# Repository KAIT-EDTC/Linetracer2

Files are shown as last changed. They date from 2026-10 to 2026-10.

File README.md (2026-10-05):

# Linetracer2 — 子ども向け教材ライントレーサー

Raspberry Pi Pico ＋ TC78H653FTG ＋ 130 モーター ×2 の、**全部足付き部品（スルーホール）で子どもが自分ではんだ付けできる**ライントレーサー。
基板そのものがシャーシで、センサー 6 個を基板の裏に直付けし、3D プリント（Bambu Lab P1S）のギヤボックス（1 段 5:1）で 130 モーターを高速に回す。
**テープ・接着剤は使わず、M3 ねじ（2 種類）と 3D プリントのツメで組み立てる。** 部品は秋月・ホームセンター・タミヤ品など、**T 番号のある店で買える定番品だけ**。

| 基板（表） | 組み立て図 |
|---|---|
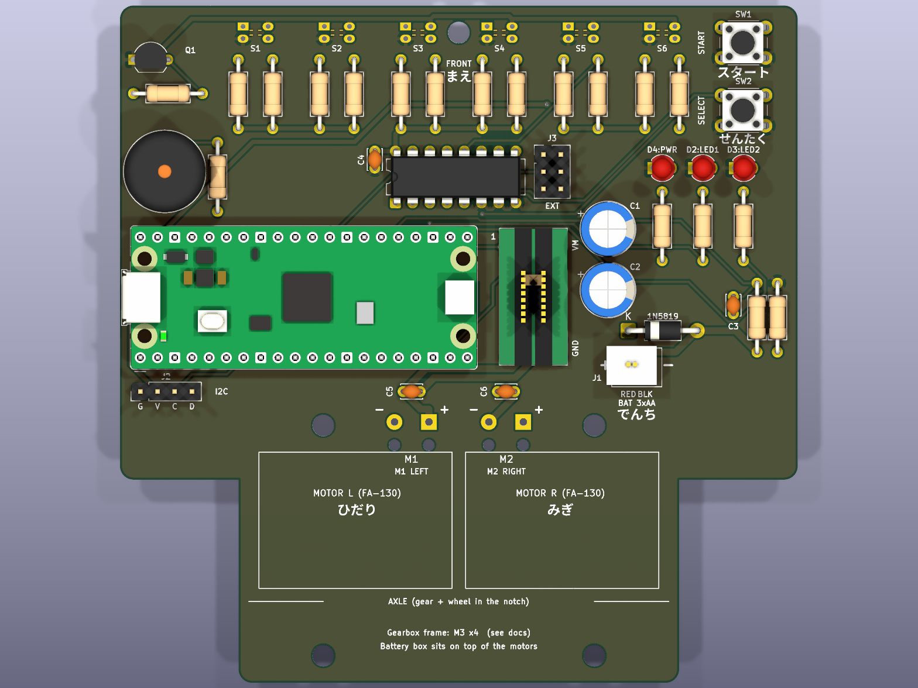
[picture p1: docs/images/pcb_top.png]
PCB top
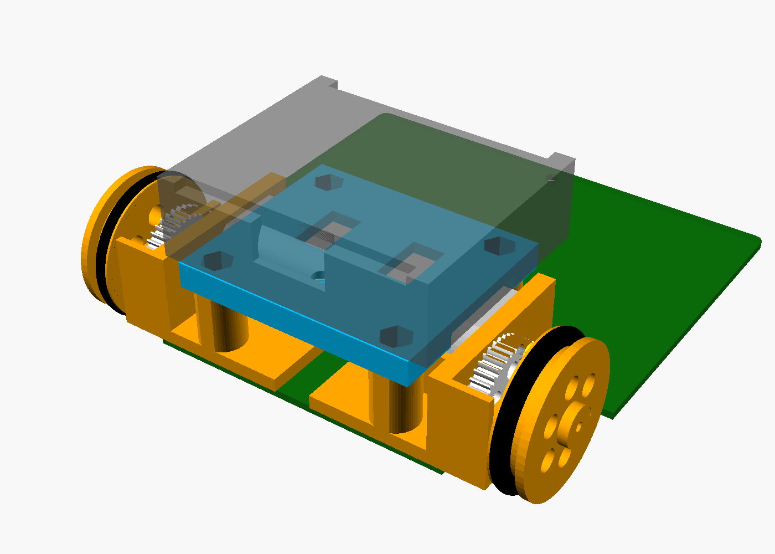
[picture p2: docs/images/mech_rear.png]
mechanics
|  |  |

| 項目 | 内容 |
|---|---|
| マイコン | Raspberry Pi Pico（Pico 2 / Pico W も可）、MicroPython |
| モータードライバ | 東芝 TC78H653FTG（秋月 AE-TC78H653FTG モジュール ¥200、スモールモード 2A×2ch） |
| モーター・駆動 | FA-130RA-2270 ×2、タミヤ 8T ピニオン → 3D プリント 40T（m0.5）1 段 5:1、車輪 φ32（O リング P-24）、車軸 真鍮 φ2 |
| センサー | フォトリフレクタ LBR-123F ×6（TC4051BP で ADC 1 本に切替、外乱光キャンセル付き） |
| 電源 | 単3×3本（アルカリ 4.5V / ニッケル水素 3.6V）。電池ボックスはデッキにねじ止め、スイッチで ON/OFF |
| 基板 | 2 層 100×100 mm、1.6 mm、全部品スルーホール（ピッチ 2.54 mm 以上、センサーのみ 1.8 mm）、**rev.A1** |
| 3D プリント | 枠 L/R・デッキ・平歯車 ×2・車輪 ×2・ツメで差し込むスキッド（PLA 約 30 g、サポート不要）。電池ボックスをツメで留めるデッキも用意（任意） |
| UI | ボタン×2（START/SELECT）、LED×3、圧電ブザー（オプション）、I2C 拡張（OLED を直挿し可） |
| 性能（計算値） | 最高速度 理論 5 m/s（ソフトで 1.5〜2.5 m/s に制限）、加速 4 m/s² でモーター電流 約 1.4 A |
| コスト（1 台） | 全部新品 約 ¥2,370、**Pico を再利用すれば 約 ¥1,500**（`docs/05_bom.md`） |

## 低コスト版「Linetracer2 Lite」（rev.L1）

標準版から部品を減らした版も用意した（詳しくは [lite/README.md](lite/README.md)）。**Lite のファイルはすべて `lite/` フォルダにまとめてあり、標準版のファイルとは混ざらない**。**3D プリント部品・ねじ・モーター・電池ボックスは標準版と共通**で、基板とソフトだけが違う。

| | 標準版 rev.A1 | Lite rev.L1 |
|---|---|---|
| Pico | ピンヘッダで付ける | **基板にじかにはんだ付け**（ヘッダなし） |
| センサー | 6 個 ＋ マルチプレクサ TC4051BP | **3 個を ADC に直結**（マルチプレクサなし） |
| ボタン / LED / ブザー | 2 / 3 / オプション | **1 / 1 / なし**（Pico の緑 LED も使える） |
| タイヤ | O リング P-24 | **TPU の印刷タイヤ** |
| はんだ付け | 約 230 か所 | **約 130 か所** |
| **1 台の部品代（全部新品）** | 約 ¥2,370 | **約 ¥2,060（−¥310、−13%）** |

> ⚠ Lite は Pico をはんだ付けしてしまうので、**Pico を回収して再利用する運用（標準版 約 ¥1,540）はできない**。子どもが持ち帰る講座なら Lite が安い。

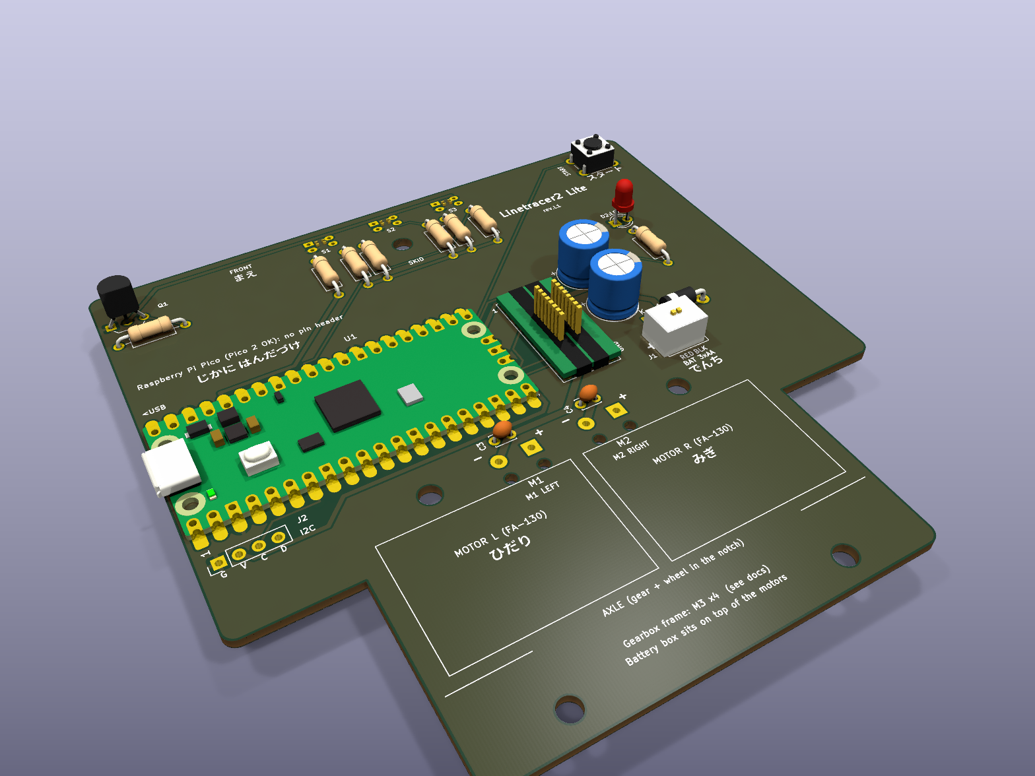
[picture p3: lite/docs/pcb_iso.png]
Lite PCB


## ドキュメント

| ファイル | 内容 |
|---|---|
| [docs/01_requirements.md](docs/01_requirements.md) | 要件定義（依頼内容・派生要件・買い方のルール・コスト目標） |
| [docs/02_concept.md](docs/02_concept.md) | 形・寸法・駆動系の計算・重心・電池 |
| [docs/03_circuit.md](docs/03_circuit.md) | 回路設計（ピン割り当て表、各ブロックの計算） |
| [docs/04_pcb.md](docs/04_pcb.md) | 基板設計（改訂履歴・配置・配線・DRC・発注方法・再生成方法） |
| [docs/05_bom.md](docs/05_bom.md) | 部品表（秋月の通販コード・買う店）、コスト、10 台分の買い物リスト |
| [docs/06_assembly.md](docs/06_assembly.md) | 組み立て手順書（はんだ付けの順番・チェック・ねじ止め・トラブル） |
| [docs/07_firmware.md](docs/07_firmware.md) | ソフトウェア（MicroPython のセットアップ、ライブラリ、PD 制御の調整） |
| [docs/08_knowledge.md](docs/08_knowledge.md) | 知見メモ（部品のクセ、買い方、KiCad/Freerouting/OpenSCAD のハマりどころ、設計判断） |
| [lite/README.md](lite/README.md) | **低コスト版 Lite**（変更点と理由、コスト比較、回路・基板・部品表・組み立て・ソフトの違い） |
| [hardware/mechanical/README.md](hardware/mechanical/README.md) | 3D プリント部品と P1S の印刷設定、ねじの一覧 |
| [hardware/mechanical/assembly.stl](hardware/mechanical/assembly.stl) | 全体を組み立てた 3D（STL、ブラウザで回して見られる） |
| [hardware/kicad/Linetracer2_pcb.step](hardware/kicad/Linetracer2_pcb.step) | 部品付き基板の 3D（STEP、Fusion 等の CAD 用） |
| [docs/Linetracer2_schematic.pdf](docs/Linetracer2_schematic.pdf) | 回路図 PDF |
| [lite/docs/Linetracer2-Lite_schematic.pdf](lite/docs/Linetracer2-Lite_schematic.pdf) | Lite の回路図 PDF |
| [docs/datasheets/README.md](docs/datasheets/README.md) | 使った部品のデータシート（リンク集） |

## フォルダ構成

```
Linetracer2/
├── README.md
├── docs/                     設計資料（Markdown）、回路図/基板 PDF、画像、データシートのリンク
├── hardware/
│   ├── kicad/                KiCad 10 プロジェクト（.kicad_pro / _sch / _pcb）
│   │   ├── lib/              自作シンボル・フットプリント（TC78H653 モジュール、LBR-123F、ブザー等）
│   │   ├── bom/              部品表 CSV（秋月の通販コード入り）
│   │   └── reports/          ERC / DRC レポート、ネットリスト
│   ├── gerber/               製造用 Gerber・ドリル
│   ├── Linetracer2_rev.A1_gerber.zip   ← 基板メーカーにそのまま渡す
│   └── mechanical/           3D プリント部品（OpenSCAD 元データ、STL、組み立て図。両方の版で共通）
├── firmware/micropython/     ライブラリ・標準プログラム・授業用サンプル
├── scripts/                  回路図・基板を生成するスクリプト（再生成用。LT2_VARIANT=lite で Lite も作る）
└── lite/                     ★ 低コスト版 Lite 一式（標準版とは別フォルダ）
    ├── README.md             Lite の設計書（変更点・コスト比較・組み立て・ソフト）
    ├── docs/                 回路図/組立図 PDF、3D 画像
    ├── hardware/             KiCad プロジェクト、Gerber（Linetracer2-Lite_rev.L1_gerber.zip）
    ├── firmware/micropython/ Lite 用ソフト（センサー 3 個・ボタン 1 個・LED 1 個）
    └── scripts/              Lite 専用の生成スクリプト（回路図・配置・シルク）
```

## 状態（2026-10-05, rev.A1）

- [x] 要件定義・構成・駆動系の計算
- [x] 回路図（ERC エラー 0・警告 0）
- [x] 基板レイアウト・配線（DRC エラー 0、未配線 0）、Gerber 出力（rev.A1: ブザーの穴を追加）
- [x] 部品選定・BOM・コスト見積り（T 番号のある店・定番品だけ）
- [x] 3D プリント部品（ねじ止めのデッキ、印刷できる 40T 平歯車、干渉チェック済み）
- [x] MicroPython ライブラリとサンプル
- [ ] **試作 1 台目の製作と実測**（センサーの感度、ギヤのかみ合い、PD ゲイン、電池の持ち）
- [ ] 試作結果を反映した rev.B（`docs/04_pcb.md` §7）
- [x] 低コスト版 Lite rev.L1 の回路図・基板（ERC 0・DRC 0・警告 0）・部品表・ソフト（2026-10-05）
- [ ] Lite の試作（Pico 直付けのしやすさ、3 センサーでの走り、`lite/README.md` §10）

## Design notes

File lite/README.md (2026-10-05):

# 低コスト版「Linetracer2 Lite」（rev.L1）

> 最終更新: 2026-10-05（rev.L1、**未製造・未試作**）
> 標準版（rev.A1）から部品を減らして安くした版。**3D プリント部品・ねじ・モーター・電池ボックス・基板の外形とねじ穴は標準版と共通**で、違うのは基板の中身とソフトだけ。
> **Lite のファイルはすべてこの `lite/` フォルダの中**（下のパスは `lite/` からの相対パス）。標準版のファイル（リポジトリ直下の `hardware/` `docs/` `firmware/`）とは混ざらない。
> 回路図: `hardware/kicad/Linetracer2-Lite.kicad_sch`（PDF: `docs/Linetracer2-Lite_schematic.pdf`）
> 製造データ: `hardware/Linetracer2-Lite_rev.L1_gerber.zip`　ソフト: `firmware/micropython/`
> 部品付き基板の 3D（STEP）: `hardware/kicad/Linetracer2-Lite_pcb.step`　組立図: `docs/Linetracer2-Lite_assembly_top.pdf` / `_bottom.pdf`

| 上面（3D） | 裏面（3D、センサー面） |
|---|---|
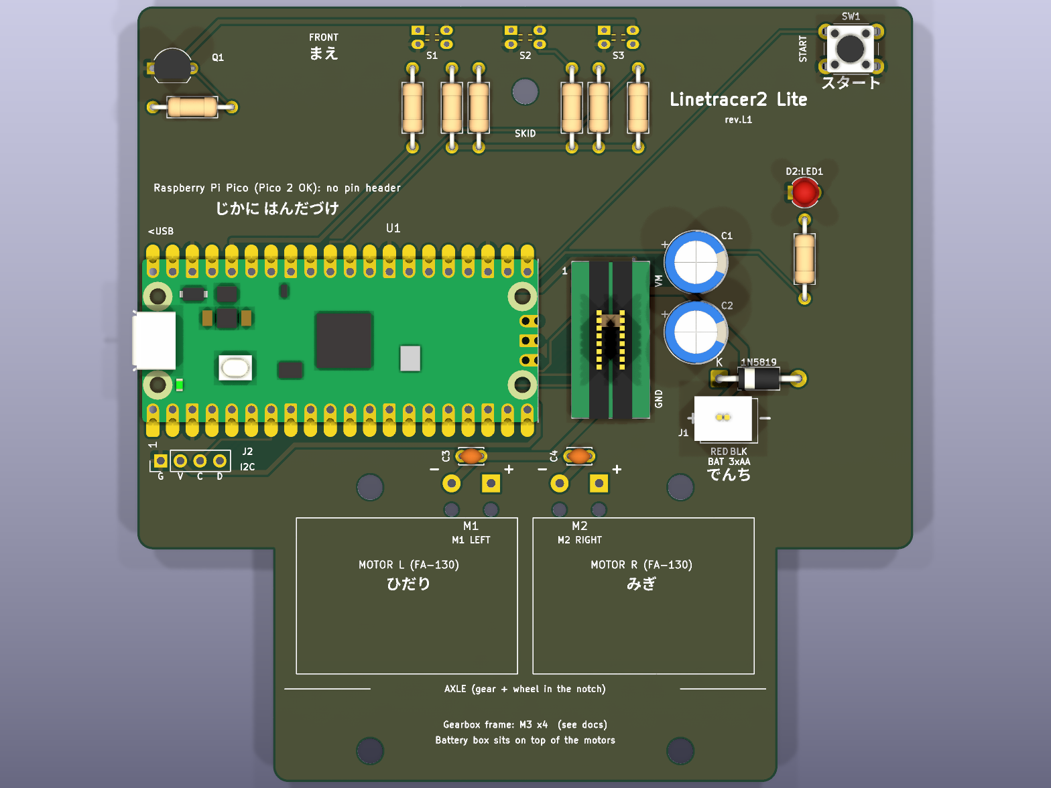
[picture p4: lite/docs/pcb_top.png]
top
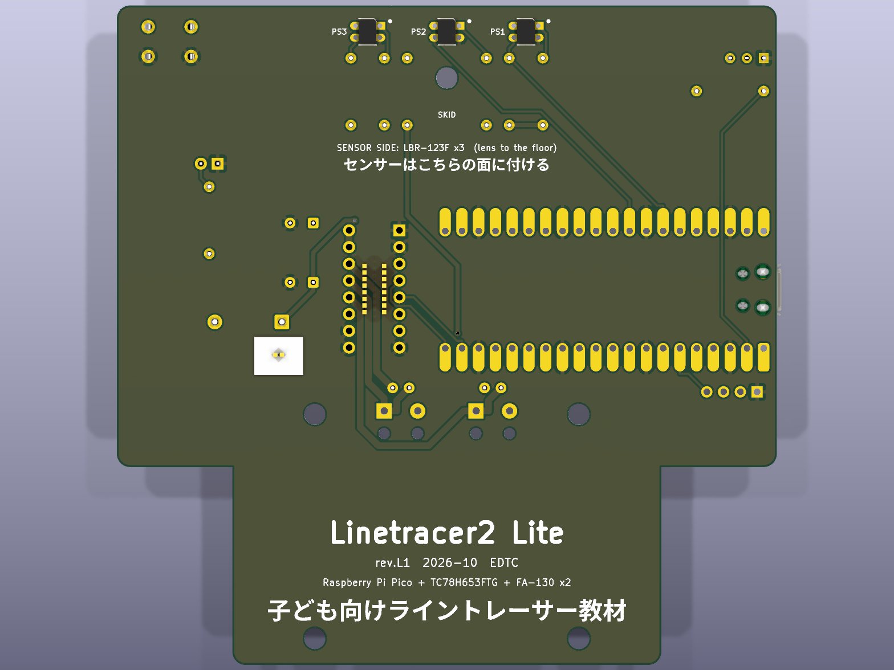
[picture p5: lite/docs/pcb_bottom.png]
bottom
|  |  |

iso

---

## 1. 依頼内容と結論

2026-10-05 の依頼: 「低コスト版を作って。ピンヘッダを付けない／センサーを 3 つに（アナログマルチプレクサいらなくなるかも）／ブザーなし／O リングなしで今ある TPU で作った O リング（タイヤ）を使う／LED 1 個／ボタン 1 個。どれくらい安くなったかも」

| | 標準版 rev.A1 | **Lite rev.L1** | 差 |
|---|---|---|---|
| **1 台の部品代（全部新品）** | 約 ¥2,370 | **約 ¥2,060** | **−¥310（−13%）** |
| Pico 以外の部品代 | 約 ¥1,540 | 約 ¥1,260 | −¥280 |
| はんだ付けの箇所 | 約 230 | **約 130** | −100（約 4 割減） |
| 基板に付ける部品（モーター線のパッドも 1 個と数える） | 44 個 | 24 個 | −20 |
| センサー | 6 個（4051 で切替） | 3 個（ADC に直結、**4051 不要**） | |
| Pico の付け方 | ピンヘッダ（80 か所） | **基板にじかにはんだ付け（40 か所）** | |
| ボタン / LED / ブザー | 2 / 3 / オプション | 1 / 1（＋Pico の LED）/ なし | |
| タイヤ | O リング P-24 | **TPU 印刷タイヤ**（`tire_tpu.stl`） | |
| 電池電圧の測り方 | 分圧抵抗 → GP27 | **Pico の中の VSYS/3（GP29）** | 部品 3 個減 |

- **アナログマルチプレクサ（TC4051BP）は不要になった**。Pico の外部 ADC はちょうど 3 本（GP26/27/28）なので、センサー 3 個を 1 本ずつ直結した。
- その代わり ADC が全部埋まるので、**電池電圧の分圧回路（R13/R14/C3）も外し、Pico の基板の中にある「VSYS/3 → GP29」**で測る（§3.2）。
- 安くなるのは主に「センサー 3 個分 ¥120」「O リング ¥80（TPU 代を引いて −¥65）」「LED・ボタン・コンデンサ・抵抗 ¥75」「ピンヘッダ ¥35」「4051 ¥15」。

### ⚠ Pico を「貸し出し・再利用」する運用だと、かえって高くなる

標準版の「¥1,500 に近づける」案は **Pico を講座で貸し出して再利用する**（基板にピンソケット／ピンヘッダで付け外しする）ことが前提だった（`../docs/05_bom.md` §3 の B 案）。
Lite は Pico を**基板にじかにはんだ付け**するので、**Pico は 1 台に 1 個、使い切り**になる。

| 運用 | 標準版 | Lite |
|---|---|---|
| Pico も持ち帰り（全部新品） | 約 ¥2,370 | **約 ¥2,060（−¥310）** |
| Pico を貸し出して再利用 | 約 ¥1,540 | できない（Pico 込みで約 ¥2,060 → **+¥520**） |

→ **「作ったロボットを子どもが持ち帰る」講座なら Lite が安い**。「Pico は回収して次の講座でも使う」なら標準版のほうが安い。

---

## 2. 変更点の一覧と理由

| # | 変更 | 理由・気をつけたこと |
|---|---|---|
| 1 | **Pico を基板にじかにはんだ付け**（ピンヘッダ ¥35 なし） | Pico は端が「キャスタレーション（半分に切った穴）」になっていて、基板に平らに置いてはんだ付けできる（公式の使い方の一つ）。はんだ付けは 80 → 40 か所。専用フットプリント `RaspberryPi_Pico_DirectSolder` を作った（§4.2） |
| 2 | Pico を標準版より 1 mm 左（基板の端寄り）に | Pico を平らに置くと USB プラグの太い部分が基板の高さまで下がる。USB コネクタの口を基板の端から 0.67 mm 外に出して、プラグが基板に当たらないようにした |
| 3 | **センサー 6 → 3 個**、x = 38 / 50 / 62 mm（12 mm 間隔） | 間隔は標準版と同じ 12 mm。19 mm の線なら、真ん中だけ黒・2 個黒・端だけ黒、の 5 段階で位置が分かる（§7） |
| 4 | **4051 マルチプレクサなし**、S1→GP28、S2→GP27、S3→GP26 | ADC 3 本に直結。基板の上で 3 本の線が交差しない順番にした |
| 5 | 電池電圧は **GP29（Pico 内部の VSYS/3）** で測る | ADC が全部埋まるため。電池電圧 ≒ VSYS + 0.3 V（D1 の電圧降下）。分圧抵抗 2 本とコンデンサ 1 個が減った |
| 6 | **ブザーなし**（BZ1・R18 を削除） | 音の代わりに LED の点滅で知らせる（ソフト） |
| 7 | **LED 1 個**（赤、GP18）。電源ランプ・黄 LED なし | 赤（¥10）は Vf が低く、3.3 V・1 kΩ でも十分光る（標準版の LED1 と同じ部品・同じ GPIO）。電源 ON はソフトで赤 LED を点けて知らせる。**Pico に付いている緑の LED（`Pin("LED")`）も 2 個目の表示に使える**（部品代 0） |
| 8 | **ボタン 1 個**（START、GP16） | 「短く押す＝スタート／ストップ」「長押し＝速さの切り替え」をソフトで分ける |
| 9 | **O リングなし → TPU の印刷タイヤ** | すでにある `tire_tpu.stl`（TPU 95A）を標準にした。車輪 `wheel.stl` は同じ |
| 10 | **スキッドの穴を (50, 4) → (50, 11) に移動** | 真ん中のセンサーが元のスキッドの位置に来るため。センサーの 7 mm 後ろ。スキッドは標準版と同じ**ツメ式**（`skid_clip_h40.stl`、ねじ・ナット不要）をそのまま使う（センサー本体とのすき間は OpenSCAD で確認、わざと 4 mm 前に寄せると重なりを検出） |
| 11 | EXT ヘッダ J3 を削除、I2C の **J2 は穴だけ残す**（ヘッダは買わない） | J3 は 4051 の空きチャンネル用だった。J2 は穴だけなので 0 円。OLED を付けたくなったら 1×4 ヘッダをはんだ付けすればよい |
| 12 | モーターの 0.1 µF（C3/C4）を 1 mm 後ろへ | Pico のパッドが外に伸びた分、間を空けた（はんだのブリッジ防止） |
| 13 | ねじ頭・スキッドのツメの下に「配線禁止エリア」 | 鉄のねじ頭（枠の 4 本、裏面）がレジストを削っても信号線とショートしないように、半径 3.5 mm には配線・ビアを通さない（GND ベタだけ可）。スキッドのツメ（表面に出る返し）の周りも同じく半径 3.6 mm を空けた |

**変えていないもの**: 基板の外形（100×100 mm、後ろの切り欠き）、枠のねじ穴 4 つ、モーター・電源まわりの配置（U2・C1・C2・D1・J1・M1・M2）、3D プリント部品の STL、ねじ（M3×20 ×4、皿 M3×8 ×2）・ツメ式スキッド、ピン番号（モーター・START・LED1・センサー LED は標準版と同じ GPIO）。

---

## 3. 回路

回路図: `docs/Linetracer2-Lite_schematic.pdf`。電源・モータードライバ・センサー 1 個分の回路は標準版と同じ（`../docs/03_circuit.md` §2・§4・§5.1）。

### 3.1 ピン割り当て（Lite）

| GPIO | Pico ピン | ネット名 | つながる先 | 標準版との違い |
|---|---|---|---|---|
| GP1 | 2 | SENS_LED_EN | R7 1kΩ → Q1 ベース（赤外 LED 3 個） | 同じ |
| GP4 / GP5 | 6 / 7 | I2C_SDA / SCL | J2（穴だけ） | 同じ |
| GP11 | 15 | MOT_STBY | U2 STBY | 同じ |
| GP12〜15 | 16, 17, 19, 20 | MOT_IN1〜4 | U2 IN1〜4 | 同じ |
| GP16 | 21 | SW1 | START ボタン（内部プルアップ） | 同じ |
| GP18 | 24 | LED1 | 赤 LED（R8 1kΩ） | 同じ |
| **GP26 / ADC0** | 31 | SENS3 | **右**センサー PS3 | 標準版は 4051 の出力 |
| **GP27 / ADC1** | 32 | SENS2 | **真ん中**センサー PS2 | 標準版は電池電圧 |
| **GP28 / ADC2** | 34 | SENS1 | **左**センサー PS1 | 標準版は EXT |
| GP29 / ADC3 | — | （Pico 内部） | VSYS/3 → **電池電圧** | 新しく使う |
| GP24 | — | （Pico 内部） | VBUS 検出（USB をつなぐと 1） | 新しく使う |
| GP25 | — | （Pico 内部） | Pico の緑 LED | 表示に使ってよい |
| GP0, 2, 3, 6〜10, 17, 19〜22 | | — | 未使用 | ブザー・SW2・LED2・MUX がなくなった |

### 3.2 電池電圧（分圧回路なし）

- Pico / Pico 2 の基板には VSYS を 1/3 にする抵抗（200 kΩ/100 kΩ）があり、GP29（ADC3）で読める（Pico の公式回路）。
- VSYS = 電池 − D1（1N5819）の電圧降下 ≒ 0.25〜0.3 V（150 mA 程度で）。ソフトでは **電池 = VSYS/3 の読み × 3 + 0.3 V** として計算（`linetracer.py` の `D1_DROP`）。誤差 ±0.1 V はモーター電圧の ±3% 程度で、速さの補正には十分。
- **USB をつないでいる間は VSYS ≒ 4.7 V（USB から）になり、電池の電圧は測れない**。GP24（VBUS 検出）で USB を見分け、「USB 接続中は電池チェックしない」ようにした。USB と電池を両方つないだときは、実際より高い電圧と思ってデューティを下げる側（安全側）にずれる。
- **Pico W / Pico 2 W は非推奨**: GP29・GP25 が無線チップ用と共用で、そのままでは電池電圧が読めない（標準版は外付けの分圧で GP27 を使うので W でも動く）。

### 3.3 センサー

- 赤外 LED 3 個 × 約 19 mA = 約 57 mA を Q1（2SC1815）で ON/OFF（外乱光キャンセルは標準版と同じ）。
- 1 回の読み取り: LED 点灯 0.3 ms → 3 個読む → 消灯 0.3 ms → 3 個読む ＝ 約 0.7 ms（標準版は MUX の切替があり約 1 ms）。

---

## 4. 基板

### 4.1 仕様（標準版との比較）

| 項目 | 標準版 rev.A1 | Lite rev.L1 |
|---|---|---|
| 外形・層・板厚 | 100×100 mm、2 層、1.6 mm | **同じ**（3D プリント部品がそのまま付く） |
| フットプリント | 52（取付穴 5 含む） | **30**（取付穴 5、未実装の J2 を含む） |
| パッド / 配線 / ビア | 193 / 300 本 / 5 | **126 / 154 本 / 2** |
| 配線の総延長 | 1,507 mm | **917 mm**（表 566 / 裏 351） |
| ERC / DRC | エラー 0、警告 3（GND の橋配線） | **エラー 0、警告 0、未接続 0** |
| 基板代 | 1 枚 ¥40〜100（JLCPCB 30 枚） | 同じ（大きさが同じなので値段も同じ） |

> **標準版（rev.A1）の基板とは別物**。Lite を作るには Lite の Gerber で基板を発注する。発注の設定は標準版と同じ（`../docs/04_pcb.md` §5）。

### 4.2 Pico 直付けのフットプリント `Linetracer2:RaspberryPi_Pico_DirectSolder`

`../scripts/gen_lib.py`（共通）の `fp_pico_direct()` で作る。

- **1 ピンに 1 つのスルーホールパッド**。穴（φ1.0）は Pico の穴の真下（ピンヘッダでも付けられる）、銅は外側へ伸ばして **Pico の端から 1.9 mm はみ出す**（4.3 × 1.7 mm の長円、穴からのオフセット 1.35 mm）。はんだごてを「基板のパッド」と「Pico の半円の穴」に同時に当てられる。
- KiCad 標準の `RaspberryPi_Pico_Common_Unspecified` から次をコピー:
  - **Pico の裏の USB コネクタの足が出る所の穴**（4 つ、銅なし）
  - **Pico の裏のむき出しのテストパッド（TP1〜TP7、デバッグ端子）の下の銅禁止エリア**（配線・ビア・ベタを置かない。Pico の裏の銅と基板の配線がショートしないように）。USB の足の穴が TP2・TP3 のエリアに少しかかるので、このエリアは「穴は可」に変えた
- 3D モデルはピンヘッダなしの `RaspberryPi_Pico.step`。

### 4.3 配置

```
 前 ─────────────────────────────────────────────────
  Q1 R7       FRONT   [S1]   [S2]   [S3]        SW1 START
                      R1 R4  R2 (SKID) R5  R3 R6      Linetracer2 Lite
                             ●(50,11)
  Raspberry Pi Pico : じかに はんだづけ                 D2 LED1
 ┌─(USB 左端)──── Pico（平らに置く）────────┐ ┌U2┐ C1     R8
 │                                           │ │  │ C2
 └───────────────────────────────────────────┘ └──┘ D1 1N5819
  J2(I2C 穴だけ)          C3  M1(+-)   C4  M2(+-)   J1(電池)
 ───(切欠)── [モーター L] [モーター R] ──(切欠)──
 後
```

- 真ん中のセンサー PS2 の抵抗（R2・R5）は、スキッドをよけて x = 44 / 56 に置いた。左右のセンサーの抵抗は標準版と同じく真後ろ。
- 空いた右前の場所に「Linetracer2 Lite」と印刷。
- 基板の生成手順・自動配線は標準版と同じ（6 回試して最短を採用、§9）。

---

## 5. 部品表（1 台分）

機械可読の部品表: `hardware/kicad/bom/Linetracer2-Lite_bom.csv`。価格は `../docs/05_bom.md` と同じ（秋月 2026-10-05 確認、≒ は目安）。

### 5.1 基板に載る部品（すべて秋月）

| 記号 | 部品 | 数 | 秋月 通販コード | 単価 | 小計 | 標準版との差 |
|---|---|----|---|---|---|---|
| U1 | Raspberry Pi Pico（Pico 2 も可、W は不可） | 1 | 116132 | ¥800 | ¥800 | ピンヘッダ不要（−¥35） |
| U2 | モータードライバーモジュール AE-TC78H653FTG | 1 | 114746 | ¥200 | ¥200 | 付属の 1×8 ピンヘッダ 2 本を使う（追加費用なし） |
| PS1〜PS3 | フォトリフレクタ LBR-123F | 3 | 116455 | ¥40 | ¥120 | −3 個（−¥120） |
| Q1 | トランジスタ 2SC1815-GR | 1 | 117089（20 個 ¥100） | ¥5 | ¥5 | |
| D1 | ショットキーダイオード 1N5819 | 1 | 117244（10 個 ¥100） | ¥10 | ¥10 | |
| R1〜R3 | 抵抗 100Ω（茶黒茶） | 3 | 125101（100 本 ¥200） | ¥2 | ¥6 | −4 本 |
| R4〜R6 | 抵抗 10kΩ（茶黒橙） | 3 | 125103（100 本 ¥100） | ¥1 | ¥3 | −5 本 |
| R7, R8 | 抵抗 1kΩ（茶黒赤） | 2 | 125102（100 本 ¥100） | ¥1 | ¥2 | −2 本 |
| C1, C2 | 電解コンデンサ 470µF 16V | 2 | 108426 | ¥10 | ¥20 | |
| C3, C4 | 積層セラミック 0.1µF（モーター用） | 2 | 113582（10 個 ¥100） | ¥10 | ¥20 | −2 個 |
| D2 | LED 3mm 赤 | 1 | 111577 | ¥10 | ¥10 | −2 個（黄・黄緑） |
| SW1 | タクトスイッチ 6mm | 1 | 108075 | ¥10 | ¥10 | −1 個 |
| J1 | XH ベース付ポスト 2P | 1 | 112247 | ¥10 | ¥10 | |
| J2 | （I2C の穴。**何も付けない**） | — | — | — | — | |
| | | | | | **¥1,216** | 標準版 ¥1,461 → **−¥245** |

使わなくなった部品: ピンヘッダ 1×40（100167）、TC4051BP（110914）、LED 黄（111639）・黄緑（111637）、圧電スピーカー（104118、オプション）。

### 5.2 機械部品

| 部品 | 数 | 買う所 | 小計 | 標準版との差 |
|---|----|---|---|---|
| DC モーター FA-130RA-2270 | 2 | 秋月 106437 | ¥300 | |
| 電池ボックス 単3×3 スイッチ・XH 付 | 1 | 秋月 112243 | ¥130 | |
| タミヤ 8T ピニオン（15289） | 2 | 模型店・ヨドバシ・Amazon | ¥77 | |
| 真鍮丸棒 φ2 × 20 mm | 2 | ホームセンター | ≒¥15 | |
| **TPU タイヤ（`tire_tpu.stl`）** | 2 | P1S で印刷（TPU 95A、2 本で約 2.1 cm³ ≒ 2.5 g） | ≒¥15 | O リング ≒¥80 の代わり（**−¥65**） |
| 3D プリント部品（PLA） | 1 式 | P1S | ≒¥90 | 同じ（STL 共通） |
| なべ小ねじ M3×20 | 4 | ホームセンター | ≒¥60 | |
| 皿小ねじ M3×8 | 2 | ホームセンター | ≒¥20 | （電池ボックス用） |
| 六角ナット M3（鉄） | 6 | ホームセンター／秋月 114372 | ≒¥50 | |
| スキッド | 1 | ツメ式（`skid_clip_h40.stl`）を印刷 | （PLA 代に含む） | 標準版と同じ |
| モーター用の電線 | 少々 | | ≒¥10 | |
| | | | **≒¥767** | 標準版 ≒¥832 → **−¥65** |

> TPU の値段は 1 kg ¥5,000 前後（¥5/g）として計算。サークルにあるフィラメントを使えば実際の出費は 0 円。

### 5.3 合計

| | 標準版 rev.A1 | Lite rev.L1 | 差 |
|---|---|---|---|
| 基板に載る部品 | ¥1,461 | ¥1,216 | −¥245 |
| 基板（JLCPCB 30 枚の目安） | ¥80 | ¥80 | 0 |
| 機械部品 | ≒¥832 | ≒¥767 | −¥65 |
| **合計（全部新品）** | **約 ¥2,370**（¥2,373） | **約 ¥2,060**（¥2,063） | **−¥310（−13%）** |
| 参考: Pico 以外 | 約 ¥1,540 | 約 ¥1,260 | −¥275 |
| 参考: 標準版でブザーも付けていた場合 | 約 ¥2,400 | 約 ¥2,060 | −¥340 |

- **¥1,500 には届かない**。いちばん大きいのは相変わらず Pico ¥800（全体の 39%）。
- 10 台分なら約 **¥3,100 安くなる**。はんだ付けの時間も約 4 割減る（§6）。

### 5.4 授業 10 台分の買い物リスト（Lite）

| 店 | 品物（通販コード） | 数 |
|----|---|----|
| 秋月 | Pico 116132 ×10、AE-TC78H653FTG 114746 ×10、LBR-123F 116455 ×30、2SC1815 117089 ×1 袋、1N5819 117244 ×1 袋、抵抗 125101・125103・125102 ×各 1 袋、470µF 108426 ×20、0.1µF 113582 ×2 袋、LED 赤 111577 ×10、タクトスイッチ 108075 ×10、XH ポスト 112247 ×10、電池ボックス 112243 ×10、FA-130RA 106437 ×20 | |
| 模型店・ヨドバシ・Amazon | タミヤ 15289 ×3 袋（真ちゅうだけ使うなら ×5 袋） | |
| ホームセンター | 真鍮丸棒 φ2 ×1 本、なべ小ねじ M3×20 ×40、皿小ねじ M3×8 ×20、六角ナット M3 ×60、（電線） | |
| ヨドバシ・Amazon | PLA フィラメント（300 g 程度）、TPU 95A（サークルの手持ちでよい、10 台で約 25 g） | |

（O リング・ピンヘッダ・TC4051BP は買わなくてよい）

---

## 6. 組み立て（標準版 `../docs/06_assembly.md` との違い）

はんだ付けの箇所: **Pico 40 ＋ モジュール 32 ＋ センサー 12 ＋ 抵抗 16 ＋ その他 21 ＋ モーター線 8 ＝ 約 130 か所**（標準版 約 230）。

### 6.1 Pico を基板にじかにはんだ付けする（いちばん大事）

> **やり直しがきかない**ので、はじめての子は先生がとなりで見る。低学年なら先生が先に付けておく。

1. **先に MicroPython を書き込んで、動くことを確かめておく**（`../docs/07_firmware.md` §1。はんだ付けした後でも書き込めるが、不良品を付けてしまうと外すのが大変）。
2. Pico を**部品面を上**にして、**USB が基板の左端に来る向き**で枠の中に置く（逆向きだと USB が基板の上に乗るのですぐ分かる）。40 個の半円の穴が、基板の 40 個の細長いパッドの真ん中に乗るように位置を合わせる。
3. Pico を指（または洗濯ばさみ）で押さえ、**対角の 2 か所（1 番と 21 番など）だけ先にはんだ付け**。Pico が浮いていないか横から見る。浮いていたら、その 1 か所を温め直しながら押さえる。
4. 残りを 1 か所ずつ: こて先を**基板のパッド（Pico の外にはみ出した所）と半円の穴の両方**に当てて 2 秒 → はんだを当てる → 半円の穴にはんだが吸い上がって山になればよい。
5. 全部付けたら、**となりのピンとのブリッジ（はんだがつながっていないか）**をルーペで見る。つながっていたら、はんだ吸い取り線で取る。
6. Pico の裏に USB コネクタの足が出ていても、基板の穴に逃げるので Pico は浮かない（はんだ付け不要）。

### 6.2 その他の違い

| 標準版の手順 | Lite |
|---|---|
| 4051（IC）・J3・ブザー・SW2・LED 2 個・R13〜R19 | **ない**（とばす） |
| センサー 6 個 | 3 個（PS1〜PS3、**基板の裏**に付けるのは同じ） |
| スキッド（ツメ式）は (50, 4) の穴 | 同じツメ式スキッドを **(50, 11) の穴**（真ん中のセンサーの 7 mm 後ろ、シルクに SKID）に押し込む |
| タイヤは O リング P-24 | **TPU の印刷タイヤ**を車輪のみぞにはめる（引っぱって伸ばしながら） |
| 電源ランプ D4 で電源 ON を確認 | 電源ランプはない。**電池のスイッチを入れて `main.py` が動くと赤 LED が点く** |
| モーターモジュールのヘッダ | 同じ（モジュールに付属のヘッダを使う） |

### 6.3 最初の確認（テスター）

1. 電池を入れずに、J1 の + と − の間がショートしていないか（標準版と同じ）。
2. Pico の 40 本のうち、**となりどうしがつながっていないか**（特に GND のとなり: 3・8・13・18・23・28・33・38 番）。
3. USB をつなぎ、Thonny で `examples/01_led_blink.py` → 赤 LED と Pico の緑 LED が交互に光れば Pico のはんだ付けは OK。

---

## 7. 性能への影響（3 センサーにしたこと）

| 項目 | 標準版（6 個） | Lite（3 個） |
|---|---|---|
| 線を見つけられる幅（19 mm 線） | 中心から ±39.5 mm | **±21.5 mm** |
| 位置の分かり方 | 6 段階＋各センサーの境目で連続的 | **5 段階**（左だけ／左＋中／中だけ／中＋右／右だけ）＋境目 |
| 位置の値 | −2500〜+2500 | −1000〜+1000（1000 = センサー 1 個分 = 12 mm は同じ） |
| 1 回の読み取り | 約 1 ms | 約 0.7 ms |
| 前の荷重（スキッド、見積り） | 約 44 g | 約 43 g（部品が減った分とスキッドが後ろに下がった分がほぼ相殺） |

- **急なカーブを速く曲がるのは苦手になる**（線がセンサーの外に出やすい）。見失ったら最後に見えた側へ強く曲がる処理は標準版と同じなので、ゆっくりならたいていのコースは走れるはず。
- ソフトの Kp は、最大の誤差が ±1000 しかないので標準版の約 2 倍を初期値にした（`main.py` の `LEVELS`）。**実機で調整が必要**（`../docs/07_firmware.md` §4 の手順と同じ）。
- 3 個だと位置が階段状に変わるので、D（微分）の値をなめらかにするフィルタを入れた（`d_f`）。
- 線幅が 15 mm でも 25 mm でも動く間隔（12 mm）にしてある。線幅が決まっていて 19 mm より太いなら、間隔を広げると見つけられる幅が増える（`gen_pcb_lite.py` の `SENSOR_X`）。

---

## 8. ソフト（`firmware/micropython/`）

標準版と同じ書き方で使えるように作った。違う所だけ:

```python
from linetracer import Robot
robot = Robot()

v = robot.sensors.read()        # [S1, S2, S3] 0(白)〜1000(黒)
pos = robot.sensors.position()  # -1000(左)〜0(真ん中)〜+1000(右)、見失うと None
kind = robot.wait_press()       # ボタンを押して離すまで待つ → "short" か "long"（0.8 秒以上）
robot.blink(3)                  # 赤 LED を 3 回点滅（ブザーの代わり）
robot.led_pico.value(1)         # Pico の緑 LED（2 個目の表示）
robot.battery.read()            # 電池電圧 [V]（USB 接続中は測れない → robot.battery.usb() で確認）
```

| 標準プログラム `main.py` | 操作 |
|---|---|
| START を短く押す（1 回目） | 自動キャリブレーション（線の上で左右に回る） |
| START を短く押す（2 回目から） | 赤 LED が 3 回点滅して走り出す。もう一度押すと止まる |
| START を長押し（Pico の緑 LED が点いたら離す） | 速さのレベル 1→2→3→1。赤 LED がレベルの数だけ点滅 |
| 赤 LED が点きっぱなし | 準備 OK（電源ランプの代わり） |
| 赤 LED が速く 5 回点滅 | 電池が少ない |

授業のサンプル: `01_led_blink.py`（赤と緑の LED）、`02_button.py`（ボタン・押した回数）、`03_sensor_monitor.py`（3 個の値）、`04_motor_test.py`（標準版と同じ）、`05_simple_tracer.py`（S1 と S3 で ON/OFF 制御）。

> 標準版の `../firmware/micropython/` は Lite では動かない（ピンと ADC の使い方が違う）。逆も同じ。

---

## 9. 作り直し方（スクリプト）

共通のスクリプト（リポジトリ直下の `scripts/`）に環境変数 `LT2_VARIANT=lite` を付けると、出力先が `lite/hardware/` になる。付けなければ標準版。Lite 専用のスクリプトは `lite/scripts/` にある。コマンドはリポジトリ直下の `scripts/` で実行する。

```bash
cd scripts
export LT2_VARIANT=lite
python3 gen_lib.py && python3 gen_3d.py && python3 gen_lib.py   # 2 回目で 3D モデルがフットプリントに入る
./kc fp upgrade ../lite/hardware/kicad/lib/Linetracer2.pretty && ./kc sym upgrade ../lite/hardware/kicad/lib/Linetracer2.kicad_sym
python3 gen_project.py
python3 ../lite/scripts/gen_schematic_lite.py && ./kc sch upgrade ../lite/hardware/kicad/Linetracer2-Lite.kicad_sch
./kc sch export netlist --format kicadsexpr -o ../lite/hardware/kicad/reports/Linetracer2-Lite.net ../lite/hardware/kicad/Linetracer2-Lite.kicad_sch
python3 build_pcb.py 6          # 配置（lite/scripts/gen_pcb_lite.py）→ 自動配線 → シルク（lite/scripts/post_pcb_lite.py）→ DRC、約 5 分
./kpy sync_pcb.py
./export_outputs.sh             # Gerber・BOM・PDF・STEP・3D 画像（lite/hardware/, lite/docs/）
```

| ファイル | 役目 |
|---|---|
| `scripts/kicad_env.py`（共通） | `LT2_VARIANT` で出力先（`hardware/kicad/` か `lite/hardware/kicad/`）とプロジェクト名を切り替え |
| `lite/scripts/gen_schematic_lite.py` | Lite の回路図 |
| `lite/scripts/gen_pcb_lite.py` | Lite の部品配置（`scripts/gen_pcb.py` の関数を使い、配置だけ差し替え）＋ねじ頭・スキッドのツメの下の配線禁止エリア |
| `lite/scripts/post_pcb_lite.py` | Lite のシルク |
| `scripts/gen_lib.py`（共通） | Pico 直付けフットプリントを追加（両方の版で共通のライブラリ） |
| `hardware/mechanical/linetracer2_mech.scad`（共通） | `-D LITE=true` でスキッド位置・センサー・TPU タイヤを Lite にして干渉チェック |

## 10. まだ確かめていないこと（試作で見る）

- [ ] Pico の直付けを子どもができるか（パッドの長さ 1.9 mm で足りるか、ブリッジしないか）
- [ ] USB プラグが基板の端に当たらないか（ケーブルの形による。当たるなら Pico をもう 0.5 mm 左へ）
- [ ] 3 センサーでどのくらいの速さ・カーブまで走れるか（`LEVELS` の調整）
- [ ] GP29 で読んだ電池電圧が、テスターで測った電池電圧と ±0.1 V で合うか（合わなければ `D1_DROP` を直す）
- [ ] TPU タイヤの外径（31.2 mm）で、センサーと床の距離がちょうどよいか（スキッド 3.5 / 4.0 / 4.5 mm で調整）
- [ ] 長押し 0.8 秒が子どもに分かりやすいか

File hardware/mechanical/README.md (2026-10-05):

# 3D プリント部品（Linetracer2 rev.A1）

サークルの **Bambu Lab P1S（0.4 mm ノズル）** で印刷する前提。STL は**印刷する向きで**書き出してあるので、Bambu Studio に読み込んでそのまま並べればよい（回転不要・サポート不要）。

assembly

| 分解図 | 側面 | ツメ版デッキ（任意） | ツメのスキッド |
|---|---|---|---|
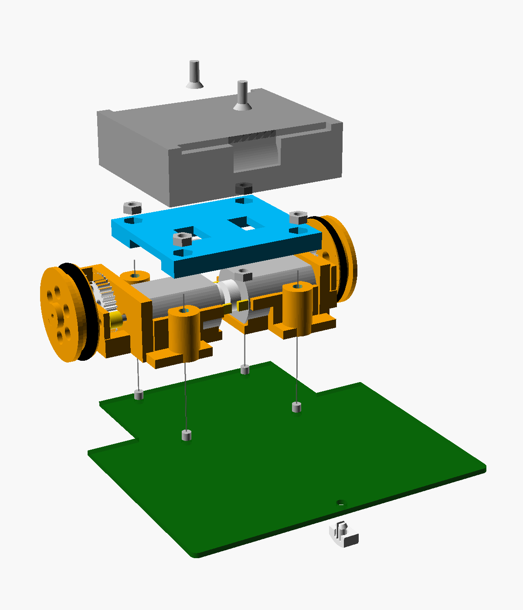
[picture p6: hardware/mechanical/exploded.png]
exploded
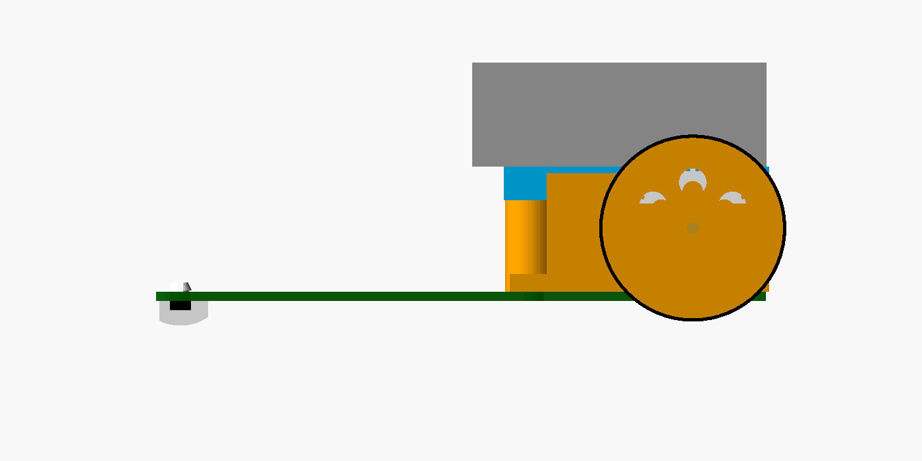
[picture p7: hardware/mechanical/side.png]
side
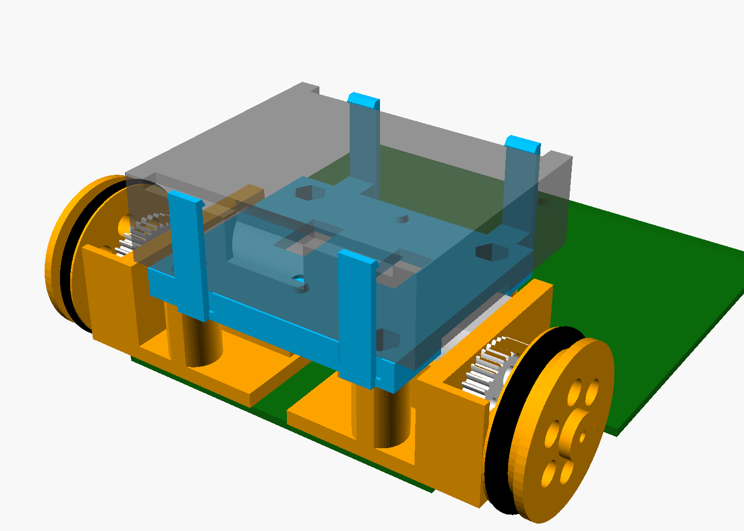
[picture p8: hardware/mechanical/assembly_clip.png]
clip
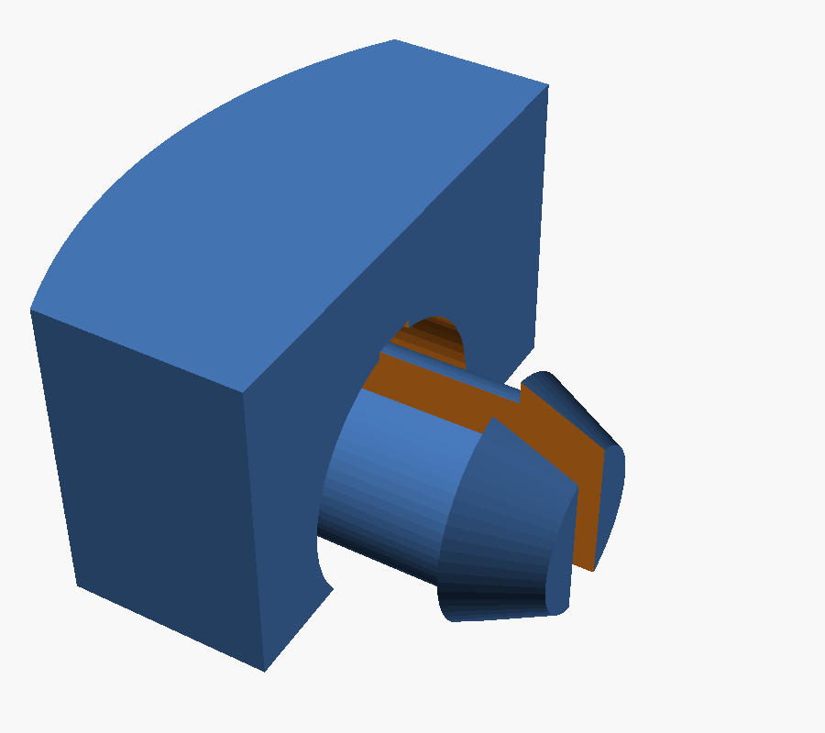
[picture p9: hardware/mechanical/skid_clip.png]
skid
|  |  |  |  |

## 1. 部品と印刷設定（1 台分）

| ファイル | 部品 | 数 | 材料 | Bambu Studio の設定 | 体積 |
|---|---|----|---|---|---|
| `frame_left.stl` / `frame_right.stl` | ギヤボックス枠（モーターのゆりかご＋軸受け＋柱） | 各 1 | PLA | 0.20 mm Standard、壁 3、インフィル 30%、サポートなし | 8.9 cm³ ×2 |
| `deck.stl` | デッキ（電池ボックスの台。モーターの押さえも兼ねる） | 1 | PLA | 0.20 mm Standard、壁 3、インフィル 25%。**上下逆さ（電池側がベッド）**で書き出し済み | 7.7 cm³ |
| `gear40.stl` | 平歯車 40T（m0.5） | 2 | PLA | **0.08 mm Extra Fine**、壁 4、インフィル 40%（壁の生成はクラシック・Arachne どちらでもよい）。ハブが上 | 1.0 cm³ ×2 |
| `wheel.stl` | 車輪（O リング P-24 をはめる） | 2 | PLA | 0.16 mm、壁 3、インフィル 40%。ハブが上 | 3.4 cm³ ×2 |
| `skid_clip_h40.stl` | **スキッド（ツメで差し込む、高さ 4.0 mm、標準）** | 1 | PETG（PLA も可） | 0.12 mm、壁 3、インフィル 40%。**横倒し**で書き出し済み（ツメが層に沿って曲がるので折れにくい） | 0.14 cm³ |
| `skid_clip_h35.stl` / `skid_clip_h45.stl` | 同（センサー高さ調整用 3.5 / 4.5 mm） | 予備 | 同上 | 同上 | |
| `skid_screw_h40.stl` | スキッド（ねじ止め版。ツメが折れたときの予備：M3×8 皿＋ナイロンナット） | (1) | 同上 | 0.12 mm、平らな面がベッド | 0.2 cm³ |
| `caster_print_h40.stl` | **ボールキャスター（試作・任意）: 玉ごと一度に印刷**（スキッドの代わり。玉は φ4、中で転がる） | (1) | PETG（PLA も可） | 0.12 mm、壁 3、インフィル 40%。**横倒し**で書き出し済み。玉と受けは最初から別々（はがす作業なし） | 0.23 cm³ |
| `caster_bead_h40.stl` | **ボールキャスター（試作・任意）: 受けだけ印刷、玉はダイソーのパール調ビーズ φ6** | (1) | PETG（PLA も可） | 同上 | 0.24 cm³ |
| `deck_clip.stl` | **ツメ版デッキ（任意・試作）**: 電池ボックスをねじではなく 4 本のツメで押さえる | (1) | PLA / PETG | 0.20 mm、壁 3、インフィル 25%。**そのままの向き（ツメが上）** | 9.0 cm³ |
| `tire_tpu.stl` | TPU タイヤ（O リングの代わり、任意） | (2) | TPU 95A | 0.20 mm、インフィル 100%、ゆっくり | 1.0 cm³ |
| `linetracer2_mech.scad` | 上記の元データ（OpenSCAD、寸法はすべてパラメータ） | — | | | |
| `assembly.stl` | **全体を組み立てた状態の 3D**（見る用。基板・モーター・電池ボックスは簡略形状、印刷しない） | — | | GitHub 上でそのまま回して見られる | |

- 1 台分 約 35 cm³（PLA 約 30 g、¥90 前後）。256 mm 角のベッドに **2〜3 台分を一度に**並べられる。
- 平歯車だけ設定が違う（細かい層）ので、**平歯車は別のプレート**にまとめて印刷する。
- 0.2 mm ノズルを持っていれば、平歯車は「0.2 mm ノズル・0.06 mm」で印刷すると歯の形がもっときれいになる（必須ではない）。

### 印刷時間の目安（Bambu Studio 2.08 の P1S 0.4 mm プロファイルでスライスした値、1 個ずつ）

| 部品 | 設定 | 時間 |
|---|---|---|
| 枠 L / R | 0.20 mm | 約 21 分 ×2 |
| デッキ | 0.20 mm | 約 16 分 |
| 車輪 | 0.16 mm | 約 13 分 ×2 |
| 平歯車 40T | 0.08 mm（壁 4・インフィル 40%） | 約 17 分 ×2 |
| スキッド（ツメ） | 0.12 mm | 約 3.5 分 |
| （ボールキャスター 玉ごと／ビーズ用） | 0.12 mm（PETG） | 約 4.5 分 ／ 約 4.5 分 |
| （ツメ版デッキ） | 0.20 mm | 約 23 分 |
| **1 台分** | | **約 2 時間**（まとめて並べるともう少し短い） |

### 平歯車は印刷できるか（スライス結果で確認済み、2026-10-05）

m0.5 の歯は先端の幅が約 0.28 mm で、0.4 mm ノズルの線（0.42 mm）より細い。そこで実際に Bambu Studio（CLI）で P1S 用にスライスし、G コードから**各層・各歯の外壁の通り道の半径**を測った。

| 壁の生成 | 結果（z = 0.24〜3.92 mm の 5 層） |
|---|---|
| クラシック（P1S プロファイルの既定） | **40 枚すべての歯が先端まで印刷される**（外形 r 約 10.50 mm、設計 10.50 mm） |
| Arachne | 同じく 40 枚すべて先端まで出る |

> 訂正（2026-10-05）: 最初の解析では「Arachne だと歯が欠ける」と書いたが、G コードの円弧命令（G2/G3、Bambu は多用する）を読み飛ばしていたための誤りだった。円弧も読む解析でやり直した結果が上の表。どちらの設定でもよい。

## 2. 固定のしかた（ねじとツメ。テープ・接着剤は使わない）

| 場所 | 固定 | 部品 | 理由 |
|---|---|---|---|
| 基板 ↔ 枠 ↔ デッキ | **ねじ** | なべ小ねじ M3×20 ×4、ナット ×4（デッキに埋める） | ロボットの重さ・ぶつかった衝撃・モーターの振動を全部受ける所。PLA のツメは荷重がかかり続けると少しずつ伸びて（クリープ）ゆるむ。またツメで基板をつかむには基板の下に回り込む形が要り、枠を平らに置いて印刷できなくなる（サポートが要り、層の向きも弱い） |
| 電池ボックス ↔ デッキ | **ねじ（標準）** または **ツメ（任意）** | 皿小ねじ M3×8 ×2、ナット ×2 ／ ツメ版デッキ `deck_clip.stl` | ねじは電池ボックスに元からある穴を使うので確実。ツメ版はねじ不要だが、電池ボックスの壁の高さ（データシートで 15.0 ±0.5 mm）に合わせる必要がある（§2.1） |
| スキッド ↔ 基板 | **ツメ（標準）** | なし（`skid_clip_h40.stl` を穴に押し込むだけ） | 床がスキッドを基板に押し付けるので、ツメは「落ちない」だけでよい。買いにくいナイロンナットが要らなくなった |
| モーター ↔ 枠 | ツメ（はめ込み）＋デッキで押さえる | — | 以前と同じ |

買う所: なべ小ねじ M3×20（ホームセンター／秋月 107437）、皿小ねじ M3×8（ホームセンター）、六角ナット M3（ホームセンター／秋月 114372）。

### 2.1 ツメ版デッキ（任意）の使い方

- 電池ボックスの**底の 2 つの穴にデッキの突起（φ3.2）が入って位置が決まり**、長い側の壁の上を **4 本のツメ**が押さえる。電池の出し入れのじゃまにはならない（ツメは壁の上にだけかかる）。
- **先に電池ボックスの壁の高さを測る**: ノギスで、ボックスの底から長い側の壁の上（両端の柱と真ん中の切り欠きの間の平らな所）まで。15.0 mm でなければ `linetracer2_mech.scad` の `BOX_SHOULDER_H` をその値にして `deck_clip.stl` を書き出し直す。
- 印刷はそのままの向き（ツメが上）。ツメは高さ方向に長い（約 20 mm）ので、曲げてもひずみは約 0.5% と小さい。PLA で折れる場合は PETG にする。
- 入れ方: 電池を抜いたボックスを上から押し込む（ツメが外に開いてパチッと閉じる）。外すときは前後のツメを外側に開いて持ち上げる。

### 2.2 ツメのスキッドの使い方

- 基板の裏から `SKID` の穴に押し込む（2 本に割れたピンがすぼまって通り、表に出たところで開いて抜けなくなる）。
- 外すときは基板の表に出たピンの先を指（またはラジオペンチ）でつまんで、すぼめながら裏へ押し出す。
- 印刷は横倒しの向き（書き出したまま）。ピンの割れ目 0.8 mm がスライス後も開いていることを G コードで確認済み。

### 2.3 ボールキャスター（試作・任意）

スキッド（そり）の代わりに、前を**転がる玉**で支える試し用。スキッドと同じ `SKID` の穴にツメで差し込む。

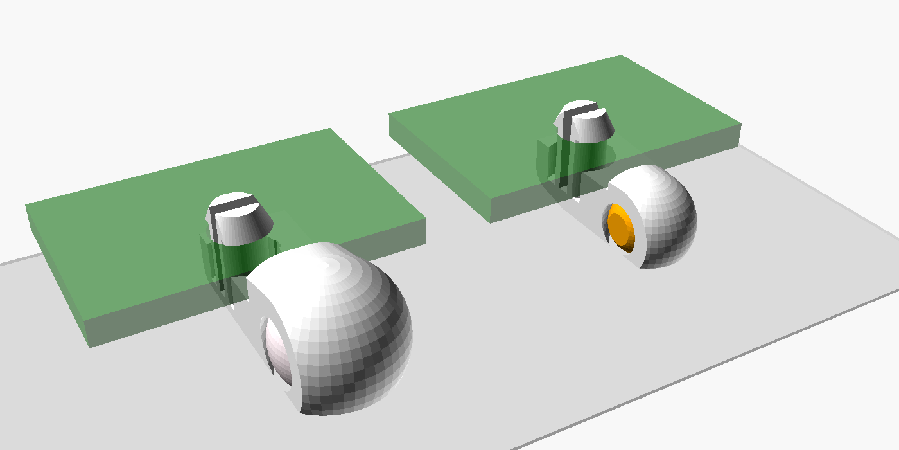
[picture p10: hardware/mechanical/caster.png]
caster


（左: ビーズ版、右: 玉ごと印刷版。緑は基板の前の端）

- 玉と受けは基板と床のすき間（4.0 mm）に入らないので、**玉は基板の前の端のすぐ前**に出し、基板の下のそり形の腕でピンまでつなぐ。腕は PS3・PS4 の間（幅 5 mm）を通る。
- 高さはスキッドの標準と同じ 4.0 mm（基板の下面〜床）。3.5 / 4.5 mm にするときは `SKID_H` を変えて書き出す。
- **標準版の基板専用**。Lite（`lite/`）はスキッドの穴が基板の端から 11 mm 奥にあり、腕が真ん中のセンサーの下を通ってしまうので使えない。

| | `caster_print_h40.stl`（玉ごと印刷） | `caster_bead_h40.stl`（ビーズ） |
|---|---|---|
| 玉 | **φ4** を受けの中で一緒に印刷（すき間 0.35 mm、玉の上は 0.55 mm） | **ダイソーのパール調ビーズ φ6** を床側から押し込む |
| 大きさ | ツメのスキッドと同じ幅 5 mm に収まり、**基板の上面より低い**。前への出っぱりは基板の端から 4.7 mm | 幅 7 mm、基板の上面より 1.6 mm 高い。前への出っぱり 7.6 mm |
| 接地点 | 基板の端の 1.5 mm 前（センサーの列の 5.5 mm 前） | 基板の端の 3.5 mm 前（センサーの列の 7.5 mm 前） |
| 床〜受けの下面 | 0.55 mm | 1.16 mm |
| 部品 | 1 個 | 受け 1 個 ＋ ビーズ 1 個 |
| 予想 | 積層の段差とベッド側の小さな平ら（φ1.9、高さ 0.25 mm）があり、なめらかには転がらない。スキッドとの比較用 | よく転がるはず。ビーズの糸穴が床に来たときに少し段がつく |

- **玉ごと印刷版**: 印刷が終わったら、玉を指で押して回し、受けから離す（G コードで、各層の玉と受けの道すじの間に約 0.27 mm の空きがあること、玉の上に空の層が 4 層あることを確認済み）。動かなければ `BALL_CLR` を 0.4 に。玉の大きさは `PRINT_BALL_D`（φ4 より大きいと受けが基板の上面より高くなる）。
- **ビーズ版**: 先にビーズの直径をノギスで測り、6.0 mm でなければ `BALL_D` を変えて書き出す。床側の口（φ5.6 = 玉 −0.4 mm）にビーズを当てて押し込む。前側の半分は切れ目（0.8 mm）で離してあり、前に少し開いてパチッと入る。抜けやすければ `BALL_LIP` を 0.5 に、入らなければ 0.3 に。
- 玉ごと印刷版は床から受けまで 0.55 mm しかないので、床の段差やコースのつなぎ目で受けがこすれるかどうかを見ること。
- 試してスキッドより良ければ標準にする。そのときは重さのバランス（`docs/02_concept.md` §4）を、実際の接地点で計算し直す。

その他の機械部品: 真鍮丸棒 φ2×20 mm（車軸）×2、タミヤ 8T ピニオン（15289）×2、O リング P-24 ×2、FA-130RA ×2、電池ボックス BH-331-3ASTH（`docs/05_bom.md`）。

## 3. 寸法の決め方

- OpenSCAD の座標は **基板の座標そのまま**（x: 右、y: 後ろ、z: 基板上面 = 0）。基板のねじ穴 (30,62)(30,96)(70,62)(70,96) と一致する。
- 車軸 y = 88、モーター軸 y = 76、どちらも基板上面から 10.4 mm（車輪 φ32 のとき）。ギヤ: ピニオン 8T・平歯車 40T（m0.5）、軸間 12 mm。
- 高さ: 柱の上面 = デッキの下面 15.0 mm、デッキ上面（電池ボックスの底）20.5 mm、モーター上面 17.9 mm（デッキの板との すき間 0.1 mm でモーターを押さえる）。電池ボックス上面は床から約 43 mm。
- **M3×20** の先はデッキの中で止まる（デッキ上面より 2 mm 下）。M3×25 を使うと電池ボックスの底に当たるので不可。
- 電池ボックス BH-331-3ASTH-150MM の底の穴（φ3.5・皿、30 mm 間隔、中央）が (50,61)(50,91) に来る。
- スキッドは幅 5 mm（ツメ版）／ φ8.6（ねじ版）で、センサー PS3・PS4 の本体の間 9.3 mm に入る。rev.A の φ10 はセンサーに 0.35 mm 重なっていたので修正した。ツメ版は進行方向に丸いそり形で、接地点はセンサーの列の真下。

### 干渉チェック（OpenSCAD）

`part="check_*"` で部品どうしの重なりを計算できる。**全部「空」になれば OK**（2026-10-05 確認済み）。

```bash
OS=~/.local/opt/openscad-2021/AppRun
for c in check_deck_motor check_deck_frame check_frame_motor check_box_frame check_deck_box \
         check_skid_sensor check_gear_frame check_wheel_frame \
         check_skidclip_sensor check_skidclip_pcb check_deckclip_motor check_deckclip_frame check_deckclip_box \
         check_caster_sensor check_caster_pcb check_caster_ball check_casterbead_ball; do
  $OS -D "part=\"$c\"" -o /tmp/$c.stl linetracer2_mech.scad 2>&1 | grep -q "empty" && echo "$c OK" || echo "$c NG"
done
```

## 4. 調整のしかた（`linetracer2_mech.scad` のパラメータ）

| 症状 | 変更 |
|---|---|
| ギヤのかみ合いがきつい／ゴリゴリ鳴る | `GEAR_BACKLASH` 0.10 → 0.15（歯を細くする）、または `MOTOR_Y` を −0.1 |
| ギヤのかみ合いがゆるい（ガタが大きい） | `GEAR_BACKLASH` → 0.05、または `MOTOR_Y` を +0.1 |
| モーターがゆりかごに入らない／ゆるい | 缶の巻き込み量 `AXIS_Z + 2.2` の `2.2` を 1.8〜2.6 で調整（上はデッキが押さえるので、ゆるめでもよい） |
| 車軸がきつい（枠の穴） | `AXLE_D + 0.15` の 0.15 を 0.25 に |
| 平歯車・車輪が車軸の上で空回り | `gear40()` の `AXLE_D - 0.05`、`wheel()` の `AXLE_D - 0.1` を 0.05 ずつ小さく |
| センサーが床から遠い／近い | スキッドを `skid_h35` / `skid_h45` に替える（`SKID_H`） |
| 車輪の径を変えたい | `AXIS_Z`（= 車輪半径 − 5.6）を変える。デッキ・柱の高さも見直す |

書き出し（例）:

```bash
OS=~/.local/opt/openscad-2021/AppRun
$OS -D 'part="frame_left"' -o frame_left.stl linetracer2_mech.scad
$OS -D 'part="skid"' -D 'SKID_H=4.0' -o skid_h40.stl linetracer2_mech.scad
$OS -D 'part="caster_bead"' -D 'BALL_D=6.0' -o caster_bead_h40.stl linetracer2_mech.scad
```

## 5. 低コスト版 Lite で使うとき

**印刷する部品（STL）は標準版とまったく同じ**（ツメ式スキッド `skid_clip_h40.stl` も同じ）。違うのは次の 2 つだけ（`lite/README.md`）。

| | 標準版 | Lite |
|---|---|---|
| タイヤ | O リング P-24（TPU タイヤも可） | **`tire_tpu.stl`（TPU 95A）を 2 個印刷** |
| スキッドを差す穴 | (50, 4)、センサー PS3・PS4 の間 | **(50, 11)**、真ん中のセンサーの 7 mm 後ろ |

干渉チェックは `-D LITE=true` を付けて上と同じ一覧を実行する（2026-10-05、ツメ式スキッドを含め標準版・Lite とも全部「空」を確認。Lite でスキッドをわざと 4 mm 前の (50, 7) に置くと重なりを検出することも確認）。

```bash
$OS -D 'LITE=true' -D 'part="check_skidclip_sensor"' -o /tmp/c.stl linetracer2_mech.scad
```

> ⚠ これは**まだ実物で試していない試作データ**。最初に 1 台分だけ印刷して、モーター・ギヤ・車軸・デッキの入り具合を確認してから量産すること（特に平歯車のかみ合い）。

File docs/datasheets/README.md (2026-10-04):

# データシート（リンク集）

PDF はメーカー・販売店の著作物なので、リポジトリには入れずにリンクだけ残す（ローカルにダウンロードした PDF は `.gitignore` で除外）。

| 部品 | 資料 | URL |
|---|---|-----|
| TC78H653FTG（東芝） | データシート（日本語） | https://akizukidenshi.com/goodsaffix/TC78H653FTG_datasheet_ja_20190129.pdf |
| AE-TC78H653FTG（秋月モジュール） | 説明書 / 回路図 | https://akizukidenshi.com/goodsaffix/AE-TC78H653FTG_20190730.pdf ／ https://akizukidenshi.com/goodsaffix/AE-TC78H653FTG_schematic_20191127.pdf |
| FA-130RA-2270 | 外形・特性 | https://akizukidenshi.com/goodsaffix/FA-130RA-2270_20190306.pdf |
| LBR-123F | データシート | https://akizukidenshi.com/goodsaffix/lbr-123f.pdf |
| 電池ボックス BH-331-3ASTH-150MM | 外形図（底の皿穴 φ3.5、30 mm 間隔） | https://akizukidenshi.com/goodsaffix/BH-331-3ASTH-150MM.pdf |
| Raspberry Pi Pico | データシート | https://datasheets.raspberrypi.com/pico/pico-datasheet.pdf |
| CD4051B（TC4051BP と同等） | データシート | https://www.ti.com/lit/ds/symlink/cd4052b.pdf |
| 2SK4017（検討のみ・不採用） | データシート | https://akizukidenshi.com/goodsaffix/2SK4017.pdf |

ダウンロード（任意）:

```bash
cd docs/datasheets
for u in \
  https://akizukidenshi.com/goodsaffix/TC78H653FTG_datasheet_ja_20190129.pdf \
  https://akizukidenshi.com/goodsaffix/AE-TC78H653FTG_20190730.pdf \
  https://akizukidenshi.com/goodsaffix/AE-TC78H653FTG_schematic_20191127.pdf \
  https://akizukidenshi.com/goodsaffix/FA-130RA-2270_20190306.pdf \
  https://akizukidenshi.com/goodsaffix/lbr-123f.pdf \
  https://akizukidenshi.com/goodsaffix/BH-331-3ASTH-150MM.pdf ; do curl -sSLO "$u"; done
```

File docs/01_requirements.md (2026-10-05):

# 01. 要件定義 — 子ども向け教材ライントレーサー「Linetracer2」

> 最終更新: 2026-10-05（rev.A1: R13〜R16 を追加、R17 低コスト版 Lite を追加）
> この文書は「何を作るか / なぜそう決めたか」を残すためのもの。設計を変えたら必ずここも更新すること。

---

## 1. 目的

- サークルで新規に作る **子ども向け教材** のライントレーサー。
- 子どもが **自分ではんだ付けして組み立て**、**プログラムを書いて走らせる** ところまでを体験できること。
- 教材としての「わかりやすさ」と、走らせたときの「速さ（楽しさ）」を両立する。

## 2. 依頼者から提示された要件（原文の要約）

| # | 要件 | 備考 |
|---|---|---|
| R1 | マイコンは **Raspberry Pi Pico** | Pico 2 も同じ形・同じピン配置なので使える設計にする |
| R2 | モーターは **130 モーター** | FA-130RA-2270 を採用 |
| R3 | モータードライバは一般的なもの。新規は **TC78H653FTG** の予定（以前は DRV8832 / DRV8835） | 依頼時の型番「TC78H6O3FTG」は実在せず、TC78H653FTG と判断 |
| R4 | センサーは任意 | フォトリフレクタ LBR-123F を採用 |
| R5 | 価格は **できれば 1,500 円以内** | → 5章でコスト見積り。純正 Pico + 秋月価格だと超える（理由と対策を明記） |
| R6 | **表面実装部品は使わない**（足のある部品＝リード部品のみ） | ICチップ自体が表面実装しか無いものは「ピンヘッダ付きモジュール」で使う |
| R7 | **なるべく速く走る** | 1.5〜2 m/s 程度を目標（7章） |
| R8 | 子どもにできない **高度なはんだ付けは避ける** | ピッチ 2.54mm 以上、大きめランド、部品点数を絞る |
| R9 | 知識・判断はすべて **Markdown で記録** | この `docs/` 以下 |
| R10 | 電源は **単3 or 単4 電池** | 単3×3本を標準、単4×3本も可 |
| R11 | **駆動軸（モーター）を増やさない**（コスト重視）。3輪でも4輪でもよい | 2モーター差動駆動 + 前側スキッド（そり）1点 = 3点接地 |
| R12 | 基板 CAD は KiCad、ツールのダウンロードは自由 | KiCad 10.0.6 (flatpak) を使用 |
| R13 | 電池ボックスなどは**テープではなくねじで固定**する（2026-10-05 追加） | M3 ねじ（20 mm と 8 mm の 2 種類）だけで全部固定。3D プリントのデッキを追加 |
| R14 | 部品は**一般的なホームセンターなどの実店舗で売っている物**。通販なら **Amazon・秋月など T 番号（適格請求書発行事業者の登録番号）のある店**。Amazon などは**安定して手に入る物**（2026-10-05 追加） | `05_bom.md` §0。海外通販・ノーブランド品をやめ、タミヤ・光（HIKARI）などの定番品にした |
| R15 | **3D プリンタ（Bambu Lab P1S）が使える**（2026-10-05 追加） | 枠・デッキ・平歯車・車輪・スキッドを印刷（`hardware/mechanical/`） |
| R16 | GitHub の **KAIT-EDTC** Organization にリポジトリを作る（2026-10-05 追加） | `KAIT-EDTC/Linetracer2` |
| R17 | **低コスト版**を別に作る: ピンヘッダなし・センサー 3 個・ブザーなし・O リングの代わりに TPU タイヤ・LED 1 個・ボタン 1 個。いくら安くなったかも示す（2026-10-05 追加） | 標準版はそのまま残し、Lite rev.L1 として追加（`lite/README.md`）。全部新品で約 ¥2,370 → 約 ¥2,060 |

## 3. 派生要件（上の要件から決めたこと）

### 3.1 電気

| # | 派生要件 | 理由 |
|---|---|---|
| D1 | 電池は **3本直列**（アルカリ 4.5V / ニッケル水素 3.6V） | Pico の VSYS 上限 5.5V 以下に収まる最大本数。4本だとアルカリ新品 6.4V で Pico を壊す |
| D2 | モーターは電池直結（VM）、Pico は **ショットキーダイオード経由**で VSYS へ | USB 接続時に USB 5V が電池へ逆流（充電）するのを防ぐ。モーターは USB からは回らない（＝机の上で暴走しない） |
| D3 | モータードライバは **秋月 AE-TC78H653FTG（¥200）** を DIP16 互換のピンヘッダで実装 | TC78H653FTG 本体は QFN16 (3mm角) で子どもには不可能。モジュールなら 2.54mm ピンをはんだ付けするだけ |
| D4 | TC78H653FTG は **スモールモード（LARGE=L）、INモード（MODE=L）** 固定 | 2モーター駆動のため。1ch あたり 2A(DC)/2.5A(10ms) |
| D5 | **STBY を GPIO で制御**する | TC78H653 は過電流検出(ISD)でラッチ停止し、復帰には STBY の L→H か電源再投入が必要（データシート p.9） |
| D6 | モーター電圧は **PWM で平均 3V 程度に制限**（ソフトで上限設定） | FA-130RA-2270 の定格範囲は 1.5〜3.0V。電池 4.5V をそのまま入れると過電流＆ブラシ寿命低下 |
| D7 | ソフトスタート（デューティを急に上げない） | 起動電流で電池電圧が落ちると Pico がリセット & ドライバの ISD が働く |
| D8 | センサーは **6個 + アナログマルチプレクサ（TC4051BP, DIP16）** で ADC 1本に集約 | Pico の外部 ADC は 3本しかない。4051 は ¥15 と安い |
| D9 | センサーの赤外 LED は **トランジスタで ON/OFF** 可能にする | 外乱光（窓からの日光など）キャンセル、消費電流削減 |
| D10 | 電池電圧を ADC で測る（分圧 1/2） | 電池が減っても同じ速さで走れるよう補正する／電池交換の目安 |
| D11 | 子どもが使う UI: **タクトスイッチ×2、LED×2、圧電スピーカ（オプション）** | 「スタート」「モード切替」「状態表示」「音」 |
| D12 | 拡張用に **I2C ヘッダ（0.96" OLED と同じピン順）** と予備アナログ入力 | 発展課題（距離センサ・表示器・マーカーセンサ追加） |

### 3.2 機械

| # | 派生要件 | 理由 |
|---|---|---|
| M1 | **基板そのものをシャーシにする** | 部品点数とコストを最小化 |
| M2 | 基板は **100 × 100 mm 以内** | JLCPCB 等で最安価格帯（5枚 $2〜） |
| M3 | 後ろ2輪駆動（左右独立）＋前にスキッド1点 | 3点接地は床に必ず全点が接地する（がたつかない） |
| M4 | 基板下面の高さ ≒ 4 mm、センサー面 ≒ 2〜3 mm | LBR-123F は検出距離が短い（数 mm）。センサーを基板の裏に直接付けられる高さにする |
| M5 | 減速は **1段平歯車 (m0.5) 8T→40T = 5:1**、車輪径 約 32 mm | 130モーターは高回転（3V 無負荷 17,400rpm）。この組合せで最高速度は十分（7章）。ピニオンはタミヤ（ミニ四駆用）、平歯車は 3D プリント |
| M6 | ギヤボックス（モーター＋車軸の保持具）は 3D プリント（P1S） | 安い・調整しやすい。柱 2 本に M3×20 を通し、基板・デッキと一緒に締める |
| M7 | 電池ボックスはモーターの上の **3D プリントのデッキに M3 皿ねじ 2 本で固定**（テープは使わない） | 基板面積を電子回路に使う。重心を駆動輪の近くにしてトラクションを稼ぐ。デッキはモーターの押さえも兼ねる |
| M8 | スキッドは**ツメで基板の穴に差し込む**。高さ違い（3.5 / 4.0 / 4.5 mm）を印刷して交換できる | センサーと床の距離を、部品を替えるだけで調整できる。ねじ・ナイロンナットが要らない |
| M9 | ツメにするのは「荷重がかからない所」だけ（スキッド、任意で電池ボックス）。基板・枠・デッキはねじ | PLA のツメは荷重がかかり続けるとゆるむ（クリープ）。基板をつかむツメは枠を平らに印刷できない |

### 3.3 子ども向け（作りやすさ）

| # | 派生要件 |
|---|---|
| K1 | 部品はすべて足付き（リード）部品。ピッチは 2.54 mm 以上（センサーだけ 1.8 mm、ランドを楕円にして間隔を確保） |
| K2 | 抵抗の値は **100Ω / 1kΩ / 10kΩ の3種類だけ** にする（カラーコード読み取りの混乱を減らす） |
| K3 | シルクに **部品番号と値（例: R1 10k）、極性（+, 赤/黒、ダイオードの帯）** を印刷 |
| K4 | 電池は **XH コネクタ付き電池ボックス**（線のはんだ付け不要・抜き差し可） |
| K5 | 逆接続しても Pico は壊れない（ダイオード）。ただしモータードライバは守れないので、組立手順書で「赤＝＋」の確認を必須にする |
| K6 | ランドは標準より大きめ（1.8〜2.0 mm）で、はんだが乗りやすいようにする |
| K7 | 機械部品の固定は **M3 ねじ（なべ M3×20 ×4、皿 M3×8 ×2、ナット）と 3D プリントのツメ**（スキッド、任意で電池ボックス）。ドライバー 1 本で組み立て・分解できる |

### 3.4 部品の買い方（R14）

| # | 派生要件 | 理由 |
|---|---|---|
| S1 | 購入先は 秋月電子通商（店頭・通販）、ホームセンター、模型店・ヨドバシ・Amazon（Amazon.co.jp 販売のタミヤ品）、モノタロウ | どこも T 番号入りの領収書（適格請求書）を出せる → 大学の会計で精算できる |
| S2 | 海外通販・ノーブランド品は使わない | 精算できない／同じ物が二度と買えないことがある |
| S3 | 店で買えない物は 3D プリントで作る（平歯車・車輪・枠・デッキ・スキッド） | P1S がある。材料はフィラメントだけ |
| S4 | 基板（PCB）だけは特注。発注先と精算方法を事前に確認する | `05_bom.md` §4 |

## 4. やらないこと（スコープ外）

- エンコーダによる速度フィードバック（コスト増。発展課題として I2C/予備ピンで後付け可能にしておく）
- 無線（Pico W / Pico 2 W を挿せばソフトだけで使える）
- 表面実装部品の手はんだ

## 5. コスト目標と結論（詳細は `05_bom.md`）

| 構成 | 合計（1台, 税込目安） |
|---|---|
| 全部新品（純正 Pico ¥800 込み、基板 ¥80） | **約 ¥2,370** |
| Pico を講座で再利用する（Pico 以外の部品代） | **約 ¥1,540** |
| 上に加えて、ねじ・O リング・フィラメントをまとめ買い | **約 ¥1,440〜1,500** |

- **純正 Pico だけで ¥800（全体の約 1/3）** あり、全部新品で ¥1,500 以内は無理。
- R14（T 番号のある店だけ）により、以前の案（海外通販の Pico 互換ボード・互換モーター）は使えなくなった。**¥1,500 にするには「Pico を再利用（貸し出し）」がほぼ唯一の方法**。
- 回路・基板はどの方法でも同じものが使える。

## 6. 前提・未確定事項（要確認）

| 項目 | 仮定 | 確認してほしいこと |
|---|---|---|
| コース | 白地に黒線（幅 19mm ビニールテープ程度） | 線幅・色・最小カーブ半径・交差やマーカーの有無 |
| 3D プリンタ | **Bambu Lab P1S（確認済み、2026-10-05）** | — |
| 子どもの年齢 | 小学校高学年〜中学生 | 低学年なら Pico は先にはんだ付け済みで配る |
| 予算 ¥1,500 | 1台あたりの部品代 | Pico を含むか・再利用するか（再利用なら約 ¥1,500） |
| 精算 | T 番号入りの領収書があればよい | 基板（海外の JLCPCB）の精算方法 |

## 7. 性能目標（概算）

- 最高速度: 1.5〜2 m/s（ソフトで制限。ハード的には 4 m/s 以上出せるギヤ比）
- 加速度: 3〜4 m/s²（モーター電流 約 1.5 A/個 以内）
- 制御周期: 1 kHz（センサー6個読み + PD 制御）
- 連続走行: アルカリ単3で 30 分以上

計算の詳細は `02_concept.md` の「駆動系の計算」を参照。

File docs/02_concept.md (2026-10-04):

# 02. 形（全体構成）と駆動系の設計

> 最終更新: 2026-10-05（rev.A1: 電池ボックスをねじ止めするデッキを追加）／ 関連: `01_requirements.md`, `04_pcb.md`, `hardware/mechanical/`

---

## 1. 全体の形

**基板そのものがシャーシ**。前にセンサー、後ろに 2 つのモーター、モーターの上に 3D プリントの**デッキ**、その上に電池ボックス。
**テープ・接着剤は使わず、M3 ねじと 3D プリントのツメで固定する**（M3×20 ×4 本で「基板・ギヤボックス枠・デッキ」をまとめて締め、電池ボックスは底の皿穴 2 か所でデッキにねじ止め）。

```
          ← 前（進行方向） y=0
 ┌──────────────────────────────────────────────┐
 │Q1 BZ  [S1]  [S2]  [S3] (ｽｷｯﾄﾞ) [S4]  [S5]  [S6]  SW1│ ← センサー6個は「裏面」
 │      R  R  R  R  R  R   R  R  R  R  R  R       SW2│   （レンズが床を向く）
 │              [ U2 4051 ]  [J3]         LED×3    │
 │ ┌──────────── Pico ────────────┐ ┌U3┐ C1        │
 │USB                             │ │  │ C2  R  R  │
 │ └──────────────────────────────┘ └──┘ D1   R R  │
 │ [J2 I2C]                     M1+-  M2+-  J1(電池)│
 ├──┐ ・(ねじ)                              (ねじ)・┌──┤ y=70
 │車│  ┌─────モーターL──────┐┌─────モーターR──────┐  │車│
 │輪│  └────────────────────┘└────────────────────┘  │輪│
 │  │ ギヤ        （この上にデッキ＋電池ボックス）  ギヤ│  │
 │  │ ─────── 車軸 y=88 ──────     ──────── 車軸 ───│  │
 └──┘ ・(ねじ)                              (ねじ)・└──┘ y=100
```

| 項目 | 値 |
|---|----|
| 基板外形 | 100 × 100 mm（後ろの左右に車輪・ギヤ用の切り欠き 17.5 × 30 mm） |
| 全幅（車輪込み） | 約 104 mm |
| 全長 | 約 104 mm（車輪が後端から 4 mm 出る） |
| 高さ | 約 43 mm（電池ボックス上面） |
| 接地 | 後輪 2 輪（駆動）＋前スキッド 1 点 ＝ **3 点接地** |
| ホイールベース | 84 mm（スキッド y=4 → 車軸 y=88） |
| トレッド | 約 96 mm |
| センサーの前出し | 車軸から 84 mm 前（＝曲がり始めを早く検出できる） |
| 質量（見積り） | 約 0.21 kg（単3アルカリ×3 込み） |

### 1.1 なぜこの形か

1. **基板＝シャーシ**: 部品が一番少なく、安い。ねじ 4 本でギヤボックスとデッキ（電池の台）が一緒に付く。
2. **センサーを基板裏に直付け**: LBR-123F（TPR-105F の後継）は検出距離が数 mm と短いので、基板を床すれすれ（下面 4 mm）にして、センサーのレンズ面を床から 2.5 mm にする。
3. **モーターと電池は後ろ（駆動輪の上）**: 重さの約 8 割が駆動輪にかかり、滑りにくい（加速・減速が速い）。
4. **センサーは最前列**: 車軸からの距離が長いほど、少しのずれを大きく検出でき、高速でも安定する。
5. **3 点接地**: 4 点だと床の凹凸でどこか 1 点が浮く。3 点なら必ず全部が接地する（＝センサー高さが一定）。
6. **ねじだけで組む**: テープは剥がれる・位置がずれる・分解できない。M3 ねじ（長さ 20 mm と 8 mm の 2 種類だけ）なら、分解して部品を交換でき、毎回同じ位置に付く。

| 前から | 後ろから | 分解図 |
|---|---|---|
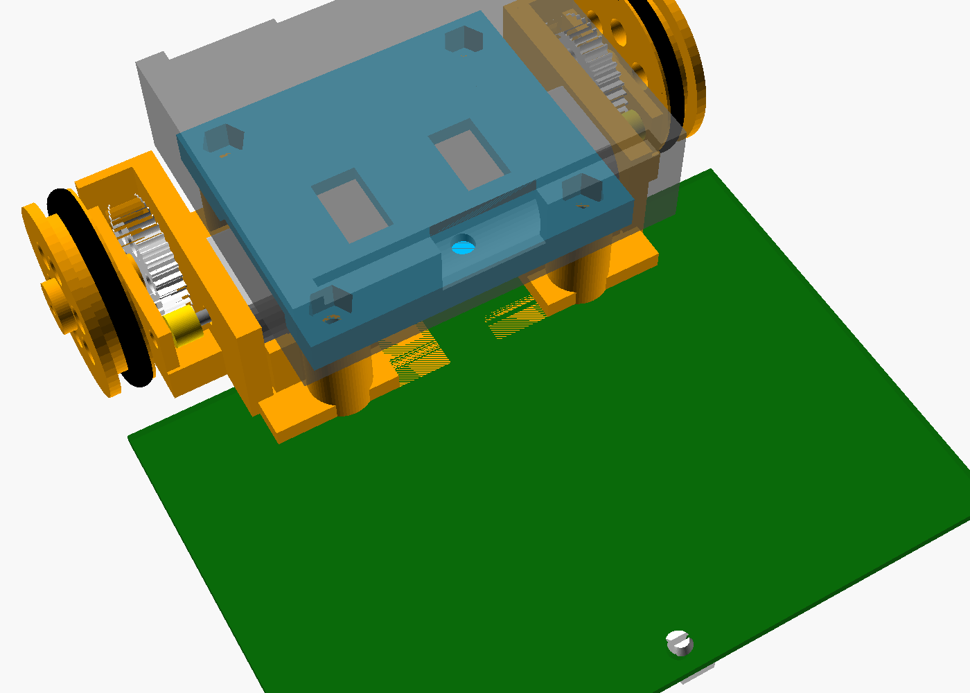
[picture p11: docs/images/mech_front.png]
front
|  | rear | exploded |

---

## 2. 高さ方向の寸法（側面図）

```
  電池ボックス (17mm)         ┌─────────────┐  ← 上面 ≒ 43mm
                             └─────────────┘  ← 底 = デッキ上面 26.1mm（M3×8 皿ねじ 2 本）
  デッキ (3D プリント)         ▀▀▀▀▀▀▀▀▀▀▀▀▀▀▀   ← 下面 23.6mm（モーターを上から押さえる）
  柱 (枠の一部)          ┃                ┃     ← 上面 20.6mm（M3×20 が基板の裏から貫通）
  モーター (厚さ15mm)  ┌───────────┐            ← 上面 23.5mm
  軸の高さ 16mm   ─ ─ ─│     ●     │─ ─ ─ ● 車軸(16mm) ⊙ 車輪 Ø32
                       └───────────┘ ギヤボックス枠
  基板 1.6mm  ════════════════════════════════  ← 上面 5.6mm / 下面 4.0mm
  センサー(1.5mm) ▄                    スキッド▼  ← レンズ面 2.5mm
  床 ─────────────────────────────────────────── 0mm
```

| 部位 | 床からの高さ |
|---|---|
| 車軸 = モーター軸 | 16.0 mm（車輪 Ø32 の半径） |
| 基板下面 | 4.0 mm（スキッドの高さで決まる） |
| 基板上面 | 5.6 mm |
| ギヤボックス枠の床板 | 基板上面からモーター下面まで 2.9 mm |
| 平歯車 40T の下端 | 基板上面より 0.1 mm 下 → **基板の切り欠きの中を通す**（切り欠きを 17.5 mm にした理由） |
| センサーのレンズ面 | 約 2.5 mm（センサーを基板にぴったり付けた場合） |
| 枠の柱の上面 ＝ デッキの下面（ねじの所） | 20.6 mm |
| デッキの板の下面（モーターの上） | 23.6 mm（モーター上面との すき間 0.1 mm） |
| デッキ上面 ＝ 電池ボックスの底 | 26.1 mm |
| 電池ボックス上面 | 約 43 mm |

**スキッド**: 3D プリントの「そり」（幅 5 mm・長さ 8 mm・高さ 4.0 mm、進行方向に半径 8 mm の丸み）。上面の 2 本に割れたピン（φ3.0、先に φ3.75 の返し）を基板の穴（φ3.2）に**押し込むだけ**で留まる（ツメ式、ねじ・ナット不要）。
床がスキッドを基板に押し付ける向きなので、ツメは「落ちない」だけでよい。接地点はセンサーの列の真下。
高さ 3.5 / 4.0 / 4.5 mm の 3 種類を用意してあり、**スキッドを替えるだけでセンサーと床の距離を調整できる**。
※ rev.A の φ10 のスキッドは、となりのセンサー（PS3・PS4）の本体に 0.35 mm 重なっていた。今のそりは幅 5 mm で、センサー本体の間（9.3 mm）に入る。

---

## 3. 駆動系

### 3.1 構成

| 部品 | 仕様 | 備考 |
|---|---|---|
| モーター | FA-130RA-2270 ×2 | 秋月 ¥150。定格 1.5〜3.0 V |
| ピニオン | m0.5 **8T**（2mm 軸穴） | **タミヤ ミニ四駆 GP No.289（15289）**。真ちゅう・プラ各 4 個入り ¥308 |
| 平歯車 | m0.5 **40T**（2mm 軸穴、車軸に圧入） | **3D プリント**（P1S、0.08 mm 層）、外径 21 mm、歯を 0.1 mm 細くして印刷誤差を逃がす |
| 減速比 | **5 : 1**（1 段） | 軸間距離 = 0.5 × (8+40) / 2 = **12 mm** |
| 車軸 | **真鍮丸棒 φ2 mm × 20 mm**（ホームセンター） | 片側 1 本ずつ。枠の穴は奥が止まりになっていて、差し込むだけで位置が決まる |
| 車輪 | 外径 約 31.4 mm（基準 32 mm） | 3D プリント＋ O リング P-24（NBR） |
| ギヤボックス枠 | 3D プリント（PLA） | `hardware/mechanical/linetracer2_mech.scad`。柱 2 本に M3×20 を通し、基板・デッキと一緒に締める |

### 3.2 モーターの特性（データシートより）

| 電圧 | 無負荷回転 | 無負荷電流 | 最高効率点 | 停動トルク | 停動電流 |
|---|---|---|---|---|---|
| 1.5 V | 9,100 rpm | 0.20 A | 6,990 rpm / 0.66 A / 0.59 mN·m | 2.55 mN·m | 2.2 A |
| 3.0 V | 17,400 rpm | 0.26 A | 13,770 rpm / 0.96 A / 0.99 mN·m | 4.71 mN·m | 3.6 A |

ここから: 巻線抵抗 R ≒ 3.0 / 3.6 = **0.83 Ω**、トルク定数 Kt ≒ 4.71 / 3.6 = **1.31 mN·m/A**。

### 3.3 速さの見積り（質量 m = 0.20 kg、車輪半径 r = 16 mm、減速比 G = 5、ギヤ効率 85%）

**最高速度**（モーター平均電圧 3.0 V 相当、軽負荷 15,000 rpm）

```
車輪回転 = 15,000 / 5 = 3,000 rpm = 50 回転/秒
速度     = 50 × π × 0.032 m = 5.0 m/s   （理論上限。実際は PWM で 1.5〜2.5 m/s に制限）
```

→ ハードとしては十分すぎるほど速い。**ソフトの「最高速度設定」で子どもの腕前に合わせて上げていける**のが教材として良い点。

**加速に必要な電流**（目標 4 m/s²）

```
必要な力       F = m·a = 0.20 × 4 = 0.80 N   → 片輪 0.40 N
車輪トルク     0.40 N × 0.016 m = 6.4 mN·m
モータートルク 6.4 / (5 × 0.85) = 1.5 mN·m
モーター電流   1.5 / 1.31 + 0.26 ≒ 1.4 A / 個   （TC78H653 スモールモード 2A 以内）
```

**注意: 起動電流**

止まっている状態で電池電圧 4.5 V をいきなり全部かけると、`I = 4.5 / (0.83 + 0.22 + 電池内部抵抗)` で **3 A 以上** 流れ、
TC78H653FTG の過電流検出（ISD、VM=4V で約 2.8 A）が働いて **出力が止まったまま（ラッチ）** になる。
→ ソフトで以下を必ず行う（`firmware/` のライブラリに実装済み）。

1. **デューティ上限**: 電池電圧を ADC で測り、モーター平均電圧が 3.0 V を超えないように上限を自動計算
2. **ソフトスタート**: デューティを 1 ms ごとに少しずつしか変えない（加速度制限）
3. **ISD 復帰**: 万一止まったら STBY を一度 L→H にして復帰

### 3.4 ギヤ比を変えたい場合

基板はねじ穴とシルクの目安線だけなので、ギヤボックス枠を作り直せば自由に変えられる。

| 組合せ | 減速比 | 軸間距離 | 最高速度(理論) | 加速時電流(4m/s²) | 向いている用途 |
|---|---|---|---|---|---|
| 8T → 40T | 5.0 | 12 mm | 5.0 m/s | 1.4 A | **標準**（速さ重視） |
| 8T → 48T | 6.0 | 14 mm | 4.2 m/s | 1.2 A | 加速・電池持ち重視 |
| 8T→36T + 10T→24T (2段) | 10.8 | — | 2.3 m/s | 0.8 A | 低学年向け（ゆっくり・壊れにくい） |

※ 車軸位置（y=88）を変えずに軸間距離が変わる場合は、モーターの位置を前後にずらした枠を作る。

### 3.5 代替案（3D プリンタが無い場合）

| 案 | 長所 | 短所 |
|----|---|---|
| タミヤ ダブルギヤボックス（12.7:1） | 確実に組める | 1 台 ¥1,000 前後でコスト超過、高さが変わりセンサー位置の再設計が必要 |
| TT ギヤードモーター（1:48、秋月 ¥350） | 安くて頑丈、130 サイズモーター入り | 遅い（4.5V で約 0.5 m/s）、車輪 65 mm で基板が高くなるため要再設計 |
| 2mm 軸＋ミニ四駆ギヤ・ホイール | 部品が手に入りやすい | 枠（軸受け）は結局自作が必要 |

---

## 4. 重さのバランス（静止時）

スキッド（y=4）と車軸（y=88）での支え方を、各部品の重さと前後位置から計算。

| 部品 | 質量 | 位置 y | 車軸まわりのモーメント |
|---|---|---|---|
| 基板 | 28 g | 45 mm | 1,204 g·mm |
| 電子部品（Pico・モジュール・センサー等） | 16 g | 30 mm | 928 |
| モーター ×2 | 36 g | 76 mm | 432 |
| ギヤ・車輪・枠 | 25 g | 85 mm | 75 |
| 電池＋ボックス | 84 g | 78 mm | 840 |
| デッキ | 6 g | 79 mm | 55 |
| ねじ・ナット・スキッド | 10 g | — | 170 |
| **合計** | **205 g** | | **3,704 g·mm** |

- スキッド荷重 = 3,704 / 84 ≒ **44 g（21%）**、駆動輪 ≒ **161 g（79%）** → 滑りにくい。
- 重心高さ ≒ 22 mm（デッキの分だけ電池が 2 mm 高くなった）。4 m/s² で加速しても前の荷重移動は 20 g 程度なので、スキッドは浮かない（ウィリーしない）。
- 横転はしない（トレッドの半分 48 mm ÷ 重心高さ 22 mm ≒ 2.2 G まで耐える。タイヤが先に滑る）。

---

## 5. 電池

| 電池 | 電圧(3本) | 内部抵抗(3本) | 特徴 |
|---|---|---|---|
| 単3 アルカリ | 4.5〜4.8 V（新品）→ 3.3 V（終止） | 約 0.5 Ω | 手に入りやすい。大電流で電圧が下がりやすい |
| 単3 ニッケル水素（eneloop 等） | 3.6〜4.2 V | 約 0.1 Ω | **おすすめ**。電圧が安定し、速さが落ちにくい |
| 単4 アルカリ / ニッケル水素 | 同上 | 単3 の約 2 倍 | 軽いが電流が取れない。練習用 |

- **4 本は絶対に使わない**（アルカリ新品 4 本 = 6.4 V で Pico の VSYS 最大 5.5 V を超える）。
- 電池ボックスは秋月「単3×3本 スイッチ付 XH コネクター付」（BH-331-3ASTH、¥130）。電源スイッチは電池ボックス側。
- 固定: ボックスの底の中央にある **φ3.5 の皿穴 2 つ（30 mm 間隔）** に M3×8 皿ねじを内側から通し、デッキに埋めたナットで締める。皿ねじの頭は底とほぼ面一なので電池に当たらない。
- 単4 を使う場合は「単4×3本 リード線・スイッチ付」（¥160）の線を J1 の穴に直接はんだ付けしてもよい（赤＝＋）。ねじ穴の位置が違うので、デッキの穴（`linetracer2_mech.scad` の `BOX_HOLES`）を合わせて印刷し直す。

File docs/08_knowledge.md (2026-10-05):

# 08. 知見メモ（ハマりどころ・調べたこと）

> 設計中に調べたこと・つまずいたことを、次に作る人のために全部残す。新しく分かったことは追記していく。

---

## A. 部品の知見

### A1. TC78H653FTG（東芝 Dual H-bridge）
- 依頼メモの「TC78H6O3FTG」という型番は存在しない → **TC78H653FTG** のこと。
- 本体は **P-VQFN16 3mm×3mm（0.5mm ピッチ、裏面パッドあり）** → 子どものはんだ付けは不可能。秋月の **AE-TC78H653FTG（¥200）** は DIP16 形状のモジュールで、ピンヘッダ（1×8 ×2）付属。モジュール上に 10µF + 0.1µF のコンデンサあり。
- モジュールのピン（上から見て、切り欠きが上）: 左列 1 LARGE / 2 MODE / 3 STBY / 4 IN4 / 5 IN3 / 6 IN1 / 7 IN2 / 8 GND、右列 16 VM / 15 VM / 14 OUT4 / 13 OUT3 / 12 OUT1 / 11 OUT2 / 10 GND / 9 GND。（資料: `docs/datasheets/README.md` のリンク）
- VM 1.8〜7.5 V（絶対最大 8 V）、スモールモード 2 A/ch (DC)、ラージモード（OUT1+2 / OUT3+4 並列）4 A。
- **過電流検出（ISD）はラッチ**。解除は STBY を L→H にするか電源再投入。しきい値は VM が低いほど下がる（VM=3 V で約 2 A、5 V で約 3.5 A）。→ 電池電圧が下がった状態で急発進すると止まりやすい。
- 入力は 37 kΩ 直列 + 150 kΩ プルダウン → 未接続・マイコン起動前は「待機・停止」。VIH は VM=3 V で 1.7 V、5 V で 2.0 V → 3.3 V ロジックで駆動できる。PWM は 500 kHz まで。
- 以前使っていた DRV8832 / DRV8835（TI）も表面実装のみ。秋月には同じようなモジュール（「DRV8832 モータードライバーモジュール」通販コード 106375、DRV8835 のモジュール）もあるが、ピン配置が違うのでこの基板には挿せない。

### A2. FA-130RA-2270（秋月 ¥150、MERCURY MOTOR 製）
- 定格 1.5 V、使用範囲 1.5〜3.0 V。
  - 1.5 V: 無負荷 9,100 rpm / 0.20 A、停動 2.2 A・2.55 mN·m
  - 3.0 V: 無負荷 17,400 rpm / 0.26 A、最高効率 13,770 rpm・0.96 A、停動 3.6 A・4.71 mN·m
- 巻線抵抗 ≒ 0.83 Ω、トルク定数 ≒ 1.31 mN·m/A。
- 3 本電池（4.5 V）では定格超え → PWM で平均 3 V 以下に制限するのが前提。
- 前側の軸受けボス φ6.0 × 1.7 mm、軸 φ2.0（前に 9.5 mm 出る）、缶 24.8 mm、幅 20.1 / 厚さ 15.0 mm。

### A3. Raspberry Pi Pico / Pico 2
- VSYS 1.8〜5.5 V（内蔵昇降圧で 3.3 V）。**電池を VSYS に直接つなぐと、USB 接続時に USB 5V が電池へ逆流**する → ショットキーダイオード必須（公式データシートの推奨回路と同じ）。
- 3V3 ピンは外部に 300 mA まで推奨。GP29(ADC3) は VSYS/3 を内部で見ている（Pico W では無線と共用）。
- 外部 ADC は GP26/27/28 の 3 本だけ → センサー 6 個は 4051 で切り替え。
- **RP2350（Pico 2）エラッタ E9**: 入力ピンの内部プルダウンを使うと約 2 V に張り付くことがある。プルダウンに頼らない回路にした。
- 秋月: Pico ¥800、Pico 2 ¥990、Pico 2 W ¥1,375（2026-10）。
- **ピンヘッダなしで基板にじかにはんだ付けできる**（端がキャスタレーション＝半分に切ったスルーホール）。基板側のパッドを Pico の端より外へ伸ばしておけば、こてを当てやすい（Lite は 1.9 mm）。KiCad 標準の `RaspberryPi_Pico_Common_Unspecified` に、**Pico の裏の USB コネクタの足の逃げ穴**と、**裏のむき出しのテストパッド（TP1〜TP7）の下の銅禁止エリア**がある → Lite のフットプリントにコピーした。そのままだと USB の足の穴（銅なし）が TP2/TP3 の禁止エリア（パッド禁止）にかかって DRC エラーになるので、エリアを「パッド可」に変えた。
- Pico を平らに付けると **USB プラグの太い部分（オーバーモールド）が基板面より下まで来る**。USB コネクタの口（Pico の端から 1.3 mm 出ている）を基板の端より外に出す必要がある（Lite は 0.67 mm 外）。
- **GP29（ADC3）= VSYS/3**（Pico の基板上の 200 kΩ/100 kΩ）、**GP24 = VBUS 検出**（USB で 1）。外付けの分圧なしで電池電圧が分かる（ショットキー D1 の分 0.3 V を足す）。ただし USB 接続中は VSYS が USB 側になり電池は測れない。**Pico W / Pico 2 W では GP29・GP24・GP25 が無線チップと共用**で、そのままでは使えない。

### A4. フォトリフレクタ LBR-123F（Letex、秋月 ¥40）
- TPR-105F の後継。ピン: 1 アノード / 2 カソード（LED）、3 エミッタ / 4 コレクタ（フォトTr）。本体 2.7×3.4×1.5 mm、足は 3.7 mm × 1.8 mm 間隔の薄い板。
- 検出距離が短い（1〜3 mm で使う）→ 基板の裏に直付けし、基板下面を床から 4 mm にした。
- IF 最大 50 mA。この設計では 19 mA。光電流は IF=20 mA・近距離で 0.1 mA 以上。
- 他の候補: RPR-220（¥110、距離が長いが高い）、LBR-127HLD（¥80）、TCRT5000（秋月になし）。

### A5. その他
- **TC4051BP（¥15）** は VDD=3.3 V でも使える（4000 シリーズ、3〜18 V）。
- **電池ボックス BH-331-3ASTH-150MM（¥130）**: XH コネクタ付きだが、どちらのピンが＋かは基板側のヘッダの向きで決まってしまう → **プラグを差してから赤線＝＋の向きでヘッダをはんだ付け**、と組立手順で決めた（シルクは左右対称）。
- **足付きの低電圧 MOSFET が手に入りにくい**: 逆接続保護に使いたかった IRLB8721 は秋月で販売終了、2SK4017 は 4V 駆動で Vgs=3 V だと約 2 A しか流れない → 逆接続保護は不採用（手順書で防ぐ）。
- 2SC1815 は東芝品は終息、秋月では互換品（UTC 2SC1815L-GR 等）が 20 個 ¥100。

### A6. 部品の買い方（2026-10-05 にサークルの方針として決定）
- **T 番号 = 適格請求書発行事業者の登録番号**（"T" ＋ 13 桁）。大学の会計で精算するには T 番号入りの領収書・請求書が要る。国税庁の公表サイトは**番号でしか検索できない**（名前では引けない）ので、領収書に書いてある番号を入れて確認する。
- Amazon は「Amazon.co.jp が販売・発送」ならアマゾンジャパン合同会社名義の適格請求書が出る。マーケットプレイスの出品者は T 番号が無いことがある。
- 秋月で買えた物（2026-10-05、すべて単品・在庫あり）: 抵抗 1/4W 100 本入り 100Ω=125101（¥200）、1kΩ=125102（¥100）、10kΩ=125103（¥100）、470µF16V Rubycon WXA φ8×9=108426（¥10）、0.1µF 2.54mm 10 個=113582（¥100）、3mm LED 赤 111577（¥10）・黄 111639（¥20）・黄緑 111637（¥10）、圧電スピーカー PKM13EPYH4000-A0=104118（¥30）、なべ M3×20 10 本=107437（¥320）、ナット M3 10 個=114372（¥120）、皿 M3×6 10 本=110246（¥80）。
- 秋月に**無かった物**: ナイロンナット、皿小ねじ M3×8（×6 と ×12 はある）→ ホームセンターかモノタロウ。秋月のねじはホームセンターの徳用袋より割高。
- LBR-123F・FA-130RA-2270 は秋月ではまとめ売りが無い（単品のみ。在庫は多い）。
- **タミヤ ミニ四駆 GP No.289「8T ピニオンギヤ（真ちゅう・プラ各 4 個）」15289、¥308** が 130 モーター（φ2 軸）用の m0.5 8T として一番手に入りやすい（模型店・ヨドバシ・Amazon）。
- O リング P-24（NBR）: カインズで ESCO EA423RB-24（10 個入り、店舗受取の取り寄せ品）、またはモノタロウ。
- 真鍮丸棒 φ2: 光（HIKARI）の約 1 m 物がホームセンターの定番。金のこで切れる（ステンレスより楽）。
- m0.5 の平歯車は売っている物だと小原歯車 DS0.5-40（ジュラコン、モノタロウ・ミスミ、数百円）くらいで高い → P1S で印刷する。

### A7. LED の色と電圧
- **525 nm の「緑」LED（InGaN）は Vf が約 3 V**。3.3 V から 1 kΩ では 0.3 mA 程度しか流れず、ほとんど光らない。電源ランプは **黄緑（570 nm、Vf≒2.1 V）** にした。赤・黄（AlGaInP）は 3.3 V でも問題ない。

### A8. 圧電ブザーの足の間隔
- KiCad 標準の `Buzzer_12x9.5RM7.6` は**足の間隔 7.6 mm**（12 mm 電磁ブザー用）。秋月の安い圧電スピーカー **PKM13EPYH4000-A0 は 5.0 mm 間隔**で挿さらない → rev.A1 でピン 1 から 5.0 mm の所に GND の穴を追加（同じピン番号の穴を 2 つ持つフットプリント。KiCad 10 では同じ番号のパッドは同じネットになり、銅でつながっている必要がある → GND ベタでつないだ）。
- 5.0 mm 側に穴を足すと 13 mm の本体の中心が左に寄り、基板の左端から約 1 mm はみ出す。右側（R18 側）に足すと R18 の本体に 1 mm 重なるので不可だった。

## B. 機械の知見

- 車輪 φ32 だと車軸は基板上面から 10.4 mm → **40T（外径 21 mm）の平歯車の下端が基板に当たる**。ギヤボックスを 3D モデルにしたときに発見 → 基板の後ろの切り欠きを 8 mm → **17.5 mm** に広げ、平歯車と外側の軸受け壁を切り欠きの中に入れた。
- モーターを「平らな面を下」にすると軸の高さ = 下面 + 7.5 mm。ギヤボックス枠の床板 2.9 mm にモーターを直接乗せると軸が 10.4 mm になり、車軸と同じ高さになる（1 段減速で軸間 12 mm）。
- 3D プリント枠: 缶の丸い側面を 2.2 mm だけ巻き込むスナップ式（はめ込むときの押し広げ約 0.14 mm/片側）。きつい/ゆるい場合は `linetracer2_mech.scad` の `AXIS_Z + 2.2` を変える。
- 重心の計算（`02_concept.md`）: 電池をモーターの上に置くと駆動輪の荷重が約 77〜79%。
- **ねじ止めの構成（rev.A1）**: 枠の柱（高さ 15 mm）に基板の裏から M3×20 を通し、柱の上のデッキに埋めたナットで締める。1 本のねじで「基板・枠・デッキ」を共締めでき、ねじの数が最少（4 本）。ナットはデッキの上面の六角穴に入れ、電池ボックスで上からふたをするので落ちない。
- ねじの長さは厳密: **M3×20 の先端は基板上面から 18.4 mm**。ナット（2.4 mm）を 15.8〜18.2 mm に置き、デッキ上面（20.5 mm）より 2 mm 下で止まるようにした。M3×25 だと電池ボックスの底に当たる。
- 電池ボックス BH-331-3ASTH の底には **φ3.5・皿（φ5）の穴が中央に 30 mm 間隔で 2 つ**ある（データシート）。M3 皿ねじの頭 φ5.5 は 0.25 mm ほど浮くが電池には当たらない。
- デッキの板の下面をモーター上面の 0.1 mm 上にして、**デッキでモーターを押さえる**。スナップ（はめ込み）だけに頼らなくてよくなった。
- 柱を缶のすぐ横に立てると、そこだけ壁が固くなってモーターがはまらない → 柱の横だけ缶の逃げを 0.3 mm 広げた（スナップの食い込み 0.14 mm を無くす）。
- **rev.A のスキッド φ10 はセンサー PS3/PS4 の本体（x 42.65〜45.35 / 54.65〜57.35）に 0.35 mm 重なっていた** → φ8.6 のねじ版（床側から皿ねじ、基板の表は**ナイロンナット**: ナットの角がセンサーのはんだから 0.2 mm しか離れない）を経て、**幅 5 mm のツメ式のそり**にした（ナイロンナット不要）。
- 平歯車は外側の壁の出っぱり（φ6）と内側の軸受けの間に入れるので、車軸を押し込むだけで位置が決まる。車軸の穴は奥が止まりで、差し込む深さも決まる。
- OpenSCAD で `intersection() { 部品A(); 部品B(); }` を書き出すと干渉チェックになる（空なら OK）。チェック自体が効いているかは、わざと重ねた条件（`-D DECK_UNDER=17.7` など）で空にならないことを確かめた。
- STL の体積は三角形ごとの符号付き体積の和で計算できる（1 台分 約 35 cm³）。
- **3D プリントのツメ（スナップ）の決め方**: ひずみ ε ≒ 1.5 × 厚さ × たわみ ÷ 長さ²。PLA は 1〜1.5% 以下、**層をまたいで曲がる向き（ツメが縦に立つ向き）は 0.5% 程度まで**に抑える。
  - スキッドのピン（厚さ 1.1 mm、たわみ 0.28 mm、長さ 5.3 mm → 約 1.6%）は、横倒しで印刷して**層に沿って曲がる向き**にした。ピンの根元は本体の中の穴（φ4.2）から立てて、曲がる長さを稼いだ。
  - ツメ版デッキのツメ（厚さ 1.4 mm、たわみ 0.85 mm、長さ約 20 mm → 約 0.5%）は縦に立つが、長くしてひずみを下げた。電池ボックスの位置は底の穴に入る突起（φ3.2・高さ 1.2 mm）で決め、ツメは押さえるだけ。
  - 電池ボックスの長い側の壁はデータシートで高さ 15.0 ±0.5 mm（両端の柱は 17 mm、真ん中に深さ 7 mm の指かけの切り欠き）。ツメはこの「肩」にかける → 実物を測って `BOX_SHOULDER_H` を合わせる。
- 干渉チェックでは、部品どうしが**面で接しているだけ**（電池ボックスがデッキに載っている等）でも「空でない（体積 0）」と出る → 片方を 0.01 mm 浮かせて調べる。チェックが本当に効くかは、わざとずらした条件（ツメのすき間をマイナスにする等）で空にならないことを確かめる。
- **印刷した m0.5 平歯車（0.4 mm ノズル）**: Bambu Studio 2.08 の CLI で P1S 用にスライスし、G コードの外壁の半径を歯ごとに測った。**壁の生成がクラシックでも Arachne でも 40 枚とも先端まで出る**。
  - ⚠ 最初は「Arachne だと歯が欠ける」と結論したが誤りだった。**Bambu の G コードは円弧命令 G2/G3 を多用する**（平歯車 1 個で約 8,000 回）のに、解析スクリプトが G0/G1 しか読んでいなかった。G コードを解析するときは G2/G3（I/J は現在位置からの中心）も必ず補間する。
- Bambu Studio CLI のコツ: `flatpak run com.bambulab.BambuStudio --slice 0 --load-settings "machine.json;process.json" --load-filaments "filament.json" --outputdir out model.stl`。プロファイルの JSON は `inherits` をたどって**全部の値を展開したもの**を渡す（展開しないと層の高さなどが既定値 0.2 mm になる）。`"from": "system"` のままにしないと「process not compatible with printer」になる。インフィル 100% を指定したら「Invalid parameter」で止まった（推奨の 壁 4・インフィル 40% なら通り、歯も 40 枚そろう）。
- **ボールキャスター（試作、2026-10-05）**: 基板の下面〜床は 4.0 mm しかなく、玉＋すき間＋屋根は入らない → 玉を**基板の前の端のすぐ前**に出し、基板の下のそり形の腕（幅 5 mm）でスキッドと同じツメのピンにつないだ。玉の位置は「受けの穴が基板の端から 0.3 mm 離れる」所から計算（`caster_yb()`）。
  - 最初は玉ごと印刷版も φ6 にしたが、受けが基板の上面より 1.7 mm 高く、前に 7.7 mm 出っぱって見た目が悪かった → **φ4 にすると、受けが基板の上面より低くなり、幅もツメのスキッドと同じ 5 mm に収まる**。腕と受けは hull でつないでそり形にした。
  - 玉が小さいほど、受けの下面と床のすき間が小さくなる（玉が抜けないように口を玉より細くするため）。φ4・すき間 0.35 で 0.55 mm、φ6 で 1.16 mm。
  - 横倒しで印刷（ピンも受けの指も層に沿って曲がる向き）。玉はベッドに 0.25 mm の平らで接し、受けはベッド側に小さな窓（玉より小さいので抜けない）がある。
  - **玉ごと印刷（プリントインプレース）**: G コードの道すじの中心どうしの間隔から線幅 0.42 mm を引いたものが実際の空き。すき間 0.3 mm の設計だと φ4 では空きが約 0.22 mm しかなかった → 0.35 mm にして約 0.27 mm。玉の上（印刷の上向き）は屋根が垂れるので、上だけ +0.2 mm（`BALL_TOP_CLR`）にした（空の層 4 層）。
  - G コードで「玉と受けが離れているか」を調べるには、玉の軸を中心にした半径で各層の道すじを並べ、いちばん大きいすき間を見る（G2/G3 の円弧も補間する）。
- 印刷時間（P1S、1 個ずつスライス）: 枠 21 分、デッキ 16 分、車輪 13 分、平歯車 17 分、スキッド 2 分 → **1 台分 約 2 時間**。

## C. 設計ツールの知見（KiCad 10 / Linux）

### C1. KiCad のインストール（sudo 不要）
```bash
flatpak remote-add --user --if-not-exists flathub https://dl.flathub.org/repo/flathub.flatpakrepo
flatpak install --user flathub org.kicad.KiCad org.kicad.KiCad.Library.Footprints//stable org.kicad.KiCad.Library.Symbols//stable
```
- 3D モデル（Packages3D、3.4 GB）も一緒に入る。全部で約 7.5 GB。
- `kicad-cli` は `flatpak run --command=kicad-cli org.kicad.KiCad`、pcbnew 入り Python は `flatpak run --command=python3 org.kicad.KiCad`（`scripts/kc`, `scripts/kpy` に用意）。
- **flatpak の中の `/tmp` は外と別物**。kicad-cli の出力先はホームの下にする。
- GUI を一度も起動していないとグローバルのライブラリ表が無く、ERC が「ライブラリが構成にない」警告を大量に出す → `/app/extensions/Library/template/{sym,fp}-lib-table` を `~/.var/app/org.kicad.KiCad/config/kicad/10.0/` にコピーすれば消える（GUI 初回起動時のウィザードと同じこと）。

### C2. スクリプトで回路図・基板を作るときの注意
- 回路図は S 式（テキスト）。古い版（KiCad 9 形式）で書いて `kicad-cli sch upgrade` で 10 形式に変換するのが楽。
- 90°/180° 回転したシンボルのフィールド文字は、KiCad が向きをトグル・寄せを反転して表示する → 90° 回転のときは角度 90・寄せ反転で保存すると横書きの左寄せになる。
- ローカルラベルのネット名は **`/VBAT` のように `/` が付く** → ネットクラスのパターンも `/VBAT`、`/MOT_OUT*` と書く（`VBAT` では当たらない）。
- pcbnew Python（10.0.6）のクセ:
  - `board.GetDrawings()` が TypeError（使わない）
  - トラックを `Remove()`/`Add()` した後、`FindFootprintByReference()` が壊れたオブジェクトを返すことがある → `GetFootprints()` から辞書を作る
  - 同じプロセスでトラックの削除・再追加を大量にした後に別の編集をすると落ちる（SIGSEGV）→ 処理を別プロセスに分け、最後は `os._exit(0)`
  - 裏面実装は `fp.Flip(pos, pcbnew.FLIP_DIRECTION_LEFT_RIGHT)` の後に `SetOrientationDegrees()`
  - 日本語シルク: `text.SetFontProp("Noto Sans CJK JP")`、**太字・1.3 mm 以上**（細いと DRC の「線の太さ不足」）、最後に `board.EmbedFonts()` でフォントを基板ファイルに埋め込む
  - **字によっては大きくしても「太さ不足」が消えない**: 「ピンヘッダなし」は 2.6 mm、「低コスト版」は 3.0 mm でも警告、「じかに はんだづけ」は 1.4 mm で OK（2026-10-05、Lite で試した）。困ったらひらがなにする
  - `fp.Models()` を for で回すと**コピー**が返る（`m.m_Show = False` が保存されない）→ `ms = fp.Models(); m = ms[i]; m.m_Show = False; ms[i] = m` と書き戻す
  - 回路図で「未実装（DNP）」「部品表から除外」にした部品は、基板のフットプリントにも `SetDNP(True)` / `SetExcludedFromBOM(True)` を付けないと DRC の回路図整合チェックで警告になる（`gen_pcb.py` の `apply_netlist` で反映）
  - 配線禁止エリア（ルールエリア）は `ZONE` の一種。`SetIsRuleArea(True)`、`SetDoNotAllowTracks/Vias(True)`。ゾーンを全部消す処理（`route_pcb.py`）では `GetIsRuleArea()` のものを残す。DSN に書き出すと Freerouting も守る。DRC では `items_not_allowed` になる
- `LT2_VARIANT=lite` のような環境変数は `flatpak run`（`./kpy`, `./kc`）の中にもそのまま渡る → 同じスクリプトで標準版と Lite を作り分けている（`kicad_env.py`）
- 秋月の TC78H653 モジュール、LBR-123F、XH 電池コネクタ、モーター線パッドは KiCad 標準ライブラリに無いので自作（`hardware/kicad/lib/Linetracer2.*`）。

### C3. 自動配線（Freerouting）
- Freerouting 2.4.1 は **Java 25 以上**が必要（Java 21 では UnsupportedClassVersionError）。Temurin の JRE を `~/.local/opt/jre25` に展開して使用。
- 実行: `java -jar freerouting-2.4.1.jar -de in.dsn -do out.ses -mp 60 --gui.enabled=false`
- KiCad から `pcbnew.ExportSpecctraDSN()` → Freerouting → `pcbnew.ImportSpecctraSES()`。
- **結果が毎回変わる**（マルチスレッド）→ 6 回試して「全部つながっている・エラー 0・配線長が最短」を採用（`scripts/build_pcb.py`）。
- GND をそのまま配線させると混雑して未配線が出る → **1 回目は GND を DSN から消して信号だけ配線 → 配線をロックして 2 回目で GND だけ配線 → 両面 GND ベタ → ベタで代用できる GND 配線を 1 本ずつ消して接続が保たれるものだけ削除**（101 本中 99 本が不要だった）。

### C4. OpenSCAD
- AppImage は FUSE が無くても `--appimage-extract` で展開して `AppRun` で動く（`~/.local/opt/openscad-2021/`）。
- `openscad -D 'part="frame_left"' -o frame_left.stl linetracer2_mech.scad`

## D. 設計判断の記録（なぜそうしたか）

| 判断 | 理由 | 代わりの案 |
|---|---|---|
| 4051 MUX でセンサー 6 個 | ADC が 3 本しかない。¥15 で DIP | センサー 3 個に減らす（MUX 不要だが位置精度が落ちる） |
| MUX のチャンネルを番号順にしない（S1=4, S2=2, S3=1, S4=0, S5=3, S6=5） | 4051 のピン配置に合わせると基板の配線が交差しない | 番号順にすると配線が増える |
| ボタン・LED を GP16〜19、ブザーと LED 切替を GP0/GP1 | Pico の向き（USB 左）で部品の近くのピンを選んだ | — |
| 逆接続保護なし | 足付きの低 Vgs MOSFET が入手困難、ダイオードは電圧降下で遅くなる | 手順書で「赤＝＋」を必ず確認 |
| 電源スイッチは電池ボックス側 | モーター電流に耐えるスイッチが付いていて安い | 基板にスライドスイッチ（電流定格が小さい） |
| 1 段減速 5:1 | 部品が少なく、子どもでも組める。速さは十分 | 2 段 10:1（電流が減り電池が長持ち、少し遅い） |
| 電池ボックスはデッキに皿ねじ 2 本、デッキ・枠・基板は M3×20 4 本で共締め | テープは剥がれる・ずれる・分解できない（依頼者の要望）。ねじは 2 種類だけで子どもが迷わない | M3 スペーサー（基板に穴を追加する必要があり、モーターの間に立てられない） |
| 平歯車は 3D プリント、ピニオンはタミヤ品 | m0.5 の平歯車は売っていても高い。ピニオン（外径 5 mm）は印刷では無理 | 小原歯車 DS0.5-40（1 個数百円） |
| 車軸は真鍮丸棒 φ2 | ホームセンターの定番品で切りやすい | ミニ四駆のシャフト（硬くて切りにくく、長さが合わない） |
| ¥1,500 は「Pico 再利用」で達成 | T 番号のある店だけだと海外の互換ボードが使えない | センサーを減らす（性能が落ちる） |
| ツメ（スナップ）はスキッドと電池ボックス（任意）だけ。基板・枠・デッキはねじのまま | ツメが向くのは荷重がかからない所。PLA のツメは荷重がかかり続けるとクリープでゆるむ。基板をつかむツメは基板の下に回り込むので、枠を平らに置いて印刷できない（サポートが要り、層の向きでツメが折れやすい） | 全部ツメ（部品は減るが、実物で何度も合わせ込みが要る） |
| 低コスト版 Lite は標準版を残したまま別の基板として追加（2026-10-05） | 標準版の性能（6 センサー）も残したい。3D プリント部品・ねじ・機械は共通にして、違いを基板とソフトだけにした | 標準版を Lite で置き換える（ブランチで分ける） |
| Lite のセンサー 3 個は ADC に直結、電池は GP29（VSYS/3） | Pico の外部 ADC 3 本をセンサーで使い切るので、分圧抵抗の代わりに Pico 内部の分圧を使う。4051・分圧抵抗・コンデンサが減る | 4051 を残して 3 個（MUX が ¥15 残り、意味が薄い） |
| Lite のスキッドはセンサーの 7 mm 後ろ（50, 11） | 真ん中のセンサーが元の位置に来る。ツメ式スキッドもそのまま使え、センサー高さの誤差は ±0.1 mm 程度 | スキッドを中心からずらす（左右非対称になる） |
| Lite の LED は GPIO の赤 1 個（電源ランプなし） | ソフトで点ければ電源ランプにもなり、Lチカにも使える。Pico の緑 LED（GP25）も 2 個目として使える | 電源ランプだけ（プログラムで光らせられない） |

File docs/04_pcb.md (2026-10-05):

# 04. 基板設計

> 最終更新: 2026-10-05（**rev.A1**）／ KiCad 10.0.6 ／ `hardware/kicad/Linetracer2.kicad_pcb`
> 製造データ: `hardware/Linetracer2_rev.A1_gerber.zip`（Gerber 7 層 + ドリル 2 ファイル）

## 改訂履歴

| 版 | 日付 | 内容 |
|----|---|---|
| rev.A | 2026-10-04 | 最初の版（未製造） |
| **rev.A1** | 2026-10-05 | ① ブザー BZ1 に **5.0 mm 間隔の穴を追加**（秋月の 13 mm 圧電スピーカー PKM13EPYH4000-A0 が挿せるように。元の 7.6 mm 間隔の穴も残した）。新しい穴は GND ベタでつながるので配線は変えていない。② D4 の部品を「黄緑 LED」に（525 nm の緑は 3.3 V で暗い）。③ シルクの版数を rev.A1 に。④ 回路図の全部品に秋月の通販コードを記入。配置・配線は rev.A と同じ |

top

| 上面（3D） | 裏面（3D、センサー面） |
|---|---|
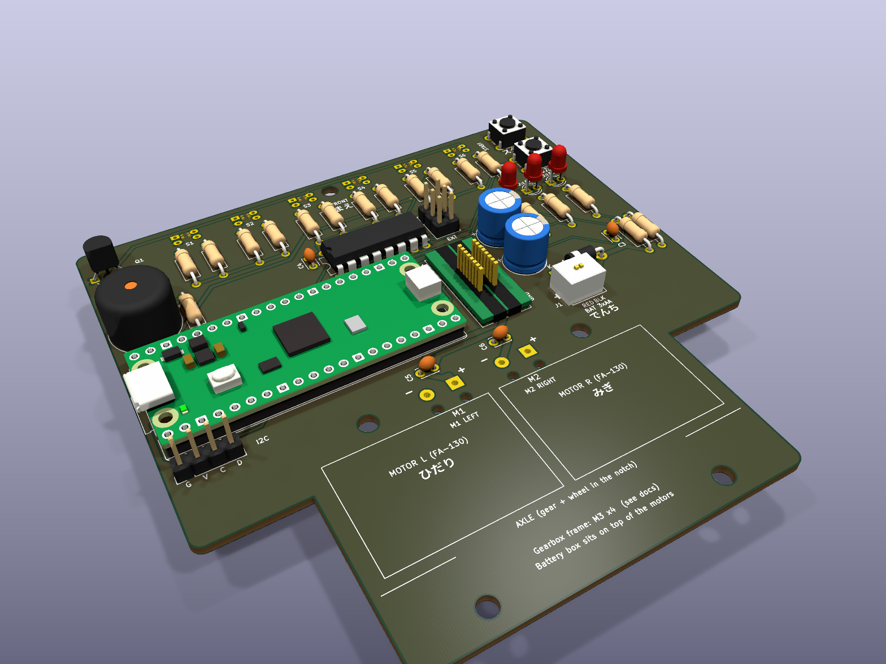
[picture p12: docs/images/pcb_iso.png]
iso
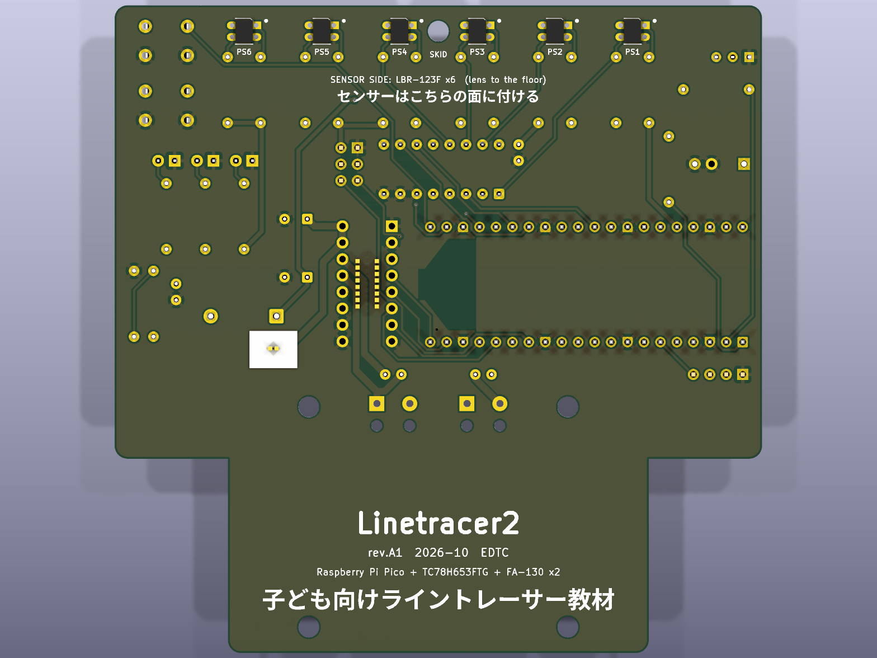
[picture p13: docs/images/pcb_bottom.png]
bottom
|  |  |

部品番号の位置（組立図、`docs/Linetracer2_assembly_top.pdf` / `_bottom.pdf`）:

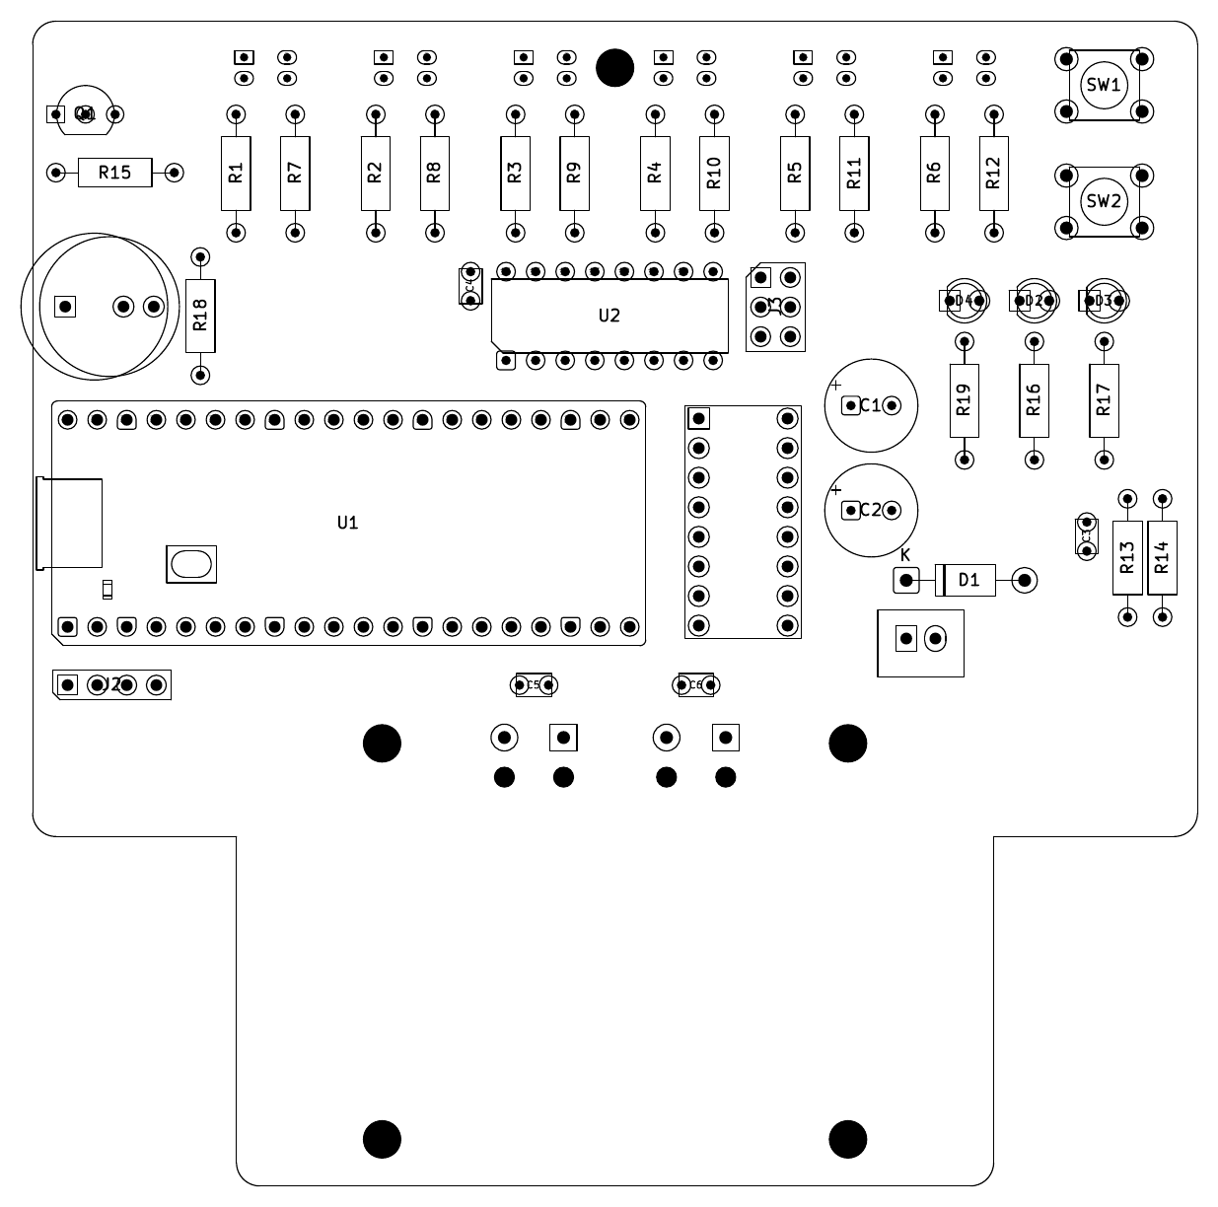
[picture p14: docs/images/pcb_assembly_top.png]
assembly


---

## 1. 基板仕様

| 項目 | 値 |
|---|----|
| 外形 | 100 × 100 mm、角 R2。後ろの左右に車輪・ギヤ用の切り欠き 17.5 × 30 mm |
| 層 | 2 層（F.Cu = 部品面、B.Cu = センサー面）、両面 GND ベタ |
| 板厚 / 銅厚 | 1.6 mm / 1 oz（35 µm） |
| 表面処理 | HASL（鉛フリー可） |
| 最小配線幅 / 間隔 | 0.3 mm / 0.2 mm（電源系 0.25 mm） |
| 最小穴 | 0.35 mm（ビア）。部品穴 0.7〜1.1 mm、M3 穴 3.2 mm（NPTH）×5、配線固定穴 1.7 mm（NPTH）×4 |
| ビア | 5 個（0.7 / 0.35 mm）|
| 部品 | 52 フットプリント（取付穴 5 を含む）、パッド 193、ネット 59 |
| 配線 | 300 本、総延長 1,507 mm（表 819 / 裏 688 mm） |

### ネットクラス（`Linetracer2.kicad_pro`）

| クラス | 線幅 | クリアランス | ネット |
|---|---|---|---|
| Motor | 1.0 mm | 0.25 mm | `/VBAT`, `/MOT_OUT1〜4` |
| Power | 0.6 mm | 0.25 mm | `/VSYS`, `+3V3`, `/LED_K`（センサー LED 6 個分 115 mA） |
| Ground | 0.3 mm（ベタが主） | 0.2 mm | `GND` |
| Default | 0.3 mm | 0.2 mm | その他の信号 |

> 1.0 mm × 35 µm の銅は 25℃上昇で約 2.5 A 流せる。モーター 1 個あたりの電流（加速時 1.4 A、ISD で最大 3 A 程度）に対して十分。

---

## 2. 部品配置の考え方

```
 前 ──────────────────────────────────────────────
  Q1 R15      [S1][S2][S3](skid)[S4][S5][S6]     SW1 START
  BZ1         R R  R R  R R      R R  R R  R R   SW2 SELECT
  R18              C4[ U2 4051 ][J3]      D4 D2 D3
 ┌──────── Pico (USB 左) ────────┐ ┌U3┐ C1   R19 R16 R17
 │                               │ │  │ C2          C3 R13 R14
 └───────────────────────────────┘ └──┘ D1 1N5819
  J2(I2C)          C5  M1(+-)   C6  M2(+-)   J1(電池)
 ───(切欠)── [モーター L] [モーター R] ──(切欠)── ← ギヤボックス枠 M3×4
 後
```

| ルール | 理由 |
|---|---|
| センサー 6 個は**裏面**、12 mm 間隔、基板の最前列（y=4） | 床から 2.5 mm。前に出すほど高速で安定 |
| センサーの抵抗はセンサーの真後ろに縦置き（左 = 100Ω、右 = 10kΩ） | 配線が最短。値を表に印刷 |
| スキッド穴は S3 と S4 の間（センサーと同じ列） | センサー高さがスキッド高さで正確に決まる |
| 4051 はセンサー列と Pico の間 | アナログ線を短く。MUX のチャンネルはピン配置に合わせて並べ替え（`03_circuit.md` 5.2） |
| Pico は USB を左端に向ける | ケーブルを横から挿せる。ADC・MUX 制御が前列、モーター制御が後列右端（ドライバの真横）に来る |
| モーター系（U3, C1, J1, モーター端子）は右後ろにまとめる | 大電流ループを小さく、アナログ部（前）から離す |
| ボタン・LED は右前の角 | 電池ボックス（モーターの上）に隠れない。子どもが触りやすい |
| 後ろ 30 mm は部品なし（モーターとギヤボックス枠の場所） | シルクでモーターの位置を表示 |

---

## 3. 配線のやり方（スクリプトで自動化）

1. `gen_pcb.py` … 外形・部品配置・取付穴（ネットリストから。回路図の UUID とリンク済み）
2. `route_pcb.py` … Specctra DSN を書き出し、**GND を除いて** Freerouting で自動配線 → 取り込み
3. 配線をロックして、**GND だけ** 2 回目の自動配線（ベタで届かないパッドの救済用）
4. 両面に GND ベタ（サーマルリリーフ 0.5 mm、孤立島は削除）
5. `post_pcb.py prune` … GND 配線を 1 本ずつ消してみて、ベタだけで接続が保てるものは削除（101 本中 99 本削除）
6. `post_pcb.py silk` … 部品番号の位置調整、子ども向けシルク（日本語・英語）、モーター位置の枠
7. DRC → 6 回試行して「未接続 0・エラー 0・配線長最短」のものを採用（`build_pcb.py`）
8. `sync_pcb.py` … 回路図の値・フィールド・ネットを基板に反映（KiCad の「回路図から基板を更新」と同じ。配置・配線は変えない）
9. `patch_revA1.py` … rev.A → rev.A1 の差分（BZ1 のフットプリント差し替え・D4 の値・版数）。配置・配線は変えない

---

## 4. チェック結果

| チェック | 結果 |
|---|---|
| ERC（回路図） | **エラー 0、警告 0** |
| DRC（基板、回路図との整合チェック込み） | **エラー 0、未接続 0、フットプリント不整合 0**、警告 3 |

警告 3 件はすべて `track_dangling`（GND の 1 mm 程度の短い配線の端が「何にもつながっていない」扱い）。
これらは**ベタの島どうしをつなぐ橋**として必要なもので（消すと未接続になる）、端がベタの中にあるので電気的には問題ない。
ビアに置き換えると周りとのクリアランスが足りないため、そのままにしている（`reports/drc.rpt`）。

---

## 5. 発注のしかた（JLCPCB の例）

1. `hardware/Linetracer2_rev.A1_gerber.zip` をアップロード
2. 設定:

| 項目 | 設定 |
|---|---|
| Base Material | FR-4 |
| Layers | 2 |
| Dimensions | 100 × 100 mm（自動認識） |
| PCB Thickness | 1.6 mm |
| PCB Color | 何色でもよい（緑が最安・最速） |
| Silkscreen | White |
| Surface Finish | HASL（with lead / lead free どちらでも） |
| Outer Copper Weight | 1 oz |
| Via Covering | Tented |
| Remove Order Number | 指定しない場合、注文番号がどこかに印刷される（気にしなければそのまま） |

- 目安: 5 枚 約 $2〜4 + 送料、30 枚でも数千円（1 枚あたり ¥40〜100）。
- **部品実装サービスは使わない**（全部子どもがはんだ付けするため）。
- JLCPCB は海外の業者で、日本の T 番号（適格請求書）は出ない前提。**大学の会計で精算できるか先に確認**する。国内業者が必要なら、同じ Gerber で国内の基板サービス（P板.com 等）に見積りを取る（`05_bom.md` §4）。

---

## 6. 再生成・修正のしかた

### 6.1 スクリプトで全部作り直す（配置や回路を大きく変えるとき）

```bash
cd scripts
python3 gen_lib.py          # 自作シンボル・フットプリント（＋ ./kc sym/fp upgrade）
python3 gen_project.py      # .kicad_pro（ルール・ネットクラス）
python3 gen_schematic.py    # 回路図  → ./kc sch upgrade / erc / export netlist
python3 build_pcb.py 6      # 配置・配線（約 15 分）
./kpy sync_pcb.py           # 回路図の値・フィールドを反映
./kpy patch_revA1.py        # rev.A の基板ファイルを rev.A1 にするときだけ（build_pcb.py で作り直したときは不要）
./export_outputs.sh         # Gerber・BOM・PDF・3D 画像
```

（コマンドの細かい順番は各スクリプト冒頭のコメント参照。KiCad は flatpak 版、`./kc` = kicad-cli、`./kpy` = KiCad 付属 Python）

> 同じスクリプトで**低コスト版 Lite**（`lite/hardware/`）も作れる: 環境変数 `LT2_VARIANT=lite` を付け、Lite 専用のスクリプトは `lite/scripts/` にある（手順は `lite/README.md` §9）。何も付けなければ標準版。

### 6.2 KiCad の画面で直す（小さな修正）

- `hardware/kicad/Linetracer2.kicad_pro` を KiCad で開いて普通に編集してよい。
- **ただし、手で直した後に `build_pcb.py` を実行すると上書きされる**。手直しを始めたら以後は GUI で管理し、スクリプトは使わない（またはスクリプト側にも同じ変更を入れる）。
- 回路図を直したら、基板エディタの「回路図から基板を更新（F8）」で反映。

---

## 7. rev.B で見直したい点（試作後に判断）

- [ ] センサー高さ（スキッド 4.0 mm）が実測で最適か。必要なら抵抗値（10 kΩ）を変える
- [ ] モーター端子のコンデンサ C5/C6 を基板からモーター側に移すか
- [ ] GND の短い橋配線（警告 3 件）をなくすよう、右上の LED まわりの配置を少し広げる
- [ ] 電池コネクタの逆差し対策（向きの決まった別コネクタ、または逆接続保護）
- [ ] 3D プリント枠の取付穴位置・切り欠きの寸法の実測確認
- [ ] ブザー（13 mm）が基板の左端から約 1 mm はみ出す。R18 を右へずらしてブザーを内側に入れる
- [ ] スキッドの穴 (50,4) がセンサー PS3/PS4 のはんだに近い（金属ナット不可）。穴を少し離すか、センサー間隔を見直す

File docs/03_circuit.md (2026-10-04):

# 03. 回路設計

> 最終更新: 2026-10-04 ／ 回路図: `hardware/kicad/Linetracer2.kicad_sch`（PDF: `docs/Linetracer2_schematic.pdf`）
> 回路図・基板はスクリプトで生成している（`scripts/gen_schematic.py`）。**手で直したら必ずスクリプト側にも反映**すること（`04_pcb.md` の「再生成のしかた」）。

---

## 1. ブロック図

```
 単3×3 (BH-331-3ASTH, SW付)                         ┌────────── 6 x LBR-123F (基板の裏) ─────────┐
   │ J1 (XH 2P)                                     │ IR-LED ──100Ω── +3V3     PT ──10kΩ── +3V3  │
   ├─ VBAT ─────────────┬──────────────┐            │   └─ LED_K ─ Q1 2SC1815 ─ GND (GP1 で ON/OFF) │
   │   C1 470µF         │ R13/R14 1/2  │            └──── SENS1..6 ────┐                             │
   │                    │   └→ GP27(ADC1)                             ▼                             
   │              D1 1N5819                              U2 TC4051BP (8ch アナログMUX) ─ COM → GP26(ADC0)
   │                    └─ VSYS ─ C2 470µF ─ Pico VSYS      ↑ A/B/C = GP20/21/22
   │                                   Pico 3V3 ──→ +3V3 (センサー, MUX, LED)
   └─ VM ─ U3 AE-TC78H653FTG ─ OUT1/2 → M1 左モーター
             ↑ IN1..IN4 = GP12..15   └ OUT3/4 → M2 右モーター
             ↑ STBY = GP11 (LARGE=MODE=GND)
   UI: SW1/SW2 (GP16/17), LED1/LED2 (GP18/19), 圧電ブザー (GP0), 電源LED (+3V3)
   拡張: J2 I2C (GP4/GP5), J3 EXT (MUX X6/X7, GP28/ADC2, GP10)
```

---

## 2. 電源

| 部品 | 値 | 役割 / 計算 |
|---|----|---|
| J1 | XH 2P (B2B-XH-A) | 電池ボックス（単3×3、スイッチ・XHコネクタ付）を差す。**向きは「赤線＝＋」で決める**（後述） |
| C1 | 470 µF 16V 電解 | モーター用の電荷だめ。TC78H653 モジュール上にも 10 µF＋0.1 µF あり |
| D1 | 1N5819（40V 1A ショットキー） | 電池 → Pico VSYS。USB をつないだとき USB 5V が電池に逆流（充電）しないようにする。Vf ≒ 0.3 V @150 mA |
| C2 | 470 µF 16V 電解 | VSYS の保持用。モーター起動で電池電圧が一瞬下がっても Pico がリセットしにくくする（150 mA 負荷で 4.0→1.8 V まで約 7 ms 保持） |
| R13/R14 | 10 kΩ / 10 kΩ | 電池電圧の 1/2 を GP27(ADC1) へ。4.8 V → 2.4 V |
| C3 | 0.1 µF | 上記の雑音除去 |
| R19 + D4 | 1 kΩ + 黄緑LED（570 nm） | 電源ランプ（+3V3 が出ていれば点灯、約 1.2 mA）。525 nm の「緑」は Vf≒3 V で 3.3 V では暗いので使わない |

### 2.1 電池の本数と電圧（再掲）

- 3 本直列のみ。アルカリ 4.5〜4.8 V / ニッケル水素 3.6〜4.2 V。
- Pico の VSYS は 1.8〜5.5 V（内蔵昇降圧 DC/DC で 3.3 V を作る）→ 電池が減っても 1.8 V まで動く。
- TC78H653FTG の VM は 1.8〜7.5 V（絶対最大 8 V）、UVLO は 1.7 V。

### 2.2 USB をつないだとき

| 状態 | Pico | モーター |
|---|---|---|
| USB のみ（電池 OFF） | USB 5V で動く（書き込み・デバッグ可） | **回らない**（VM=0V） ← 机の上で暴走しない |
| 電池のみ | 電池で動く | 回る |
| 両方 | 電圧の高い方から（D1 と Pico 内蔵ダイオードで自動切替） | 回る |

### 2.3 逆接続について（重要）

- Pico は D1 で守られる（逆電圧がかからない）。
- **モータードライバ（U3）と C1 は守れない**。電池ボックスの XH コネクタは差し込み方向は決まっているが、**基板側のヘッダーを逆向きにはんだ付けすると逆接続になる**。
- 対策: ヘッダーをはんだ付けする前に **電池ボックスのプラグを差し込み、赤い線が「＋」側に来る向き** でヘッダーを置いてからはんだ付けする（組立手順書に記載）。シルクは左右対称で、向きを決めるのは赤線。
- 逆接続保護 FET（低ドロップの N-ch MOSFET）も検討したが、3 本電池の低い電圧で十分 ON する足付き MOSFET が秋月で入手困難（IRLB8721 は販売終了、2SK4017 は Vgs=3V で 2A 程度しか流れない）なので不採用。

---

## 3. マイコン（Raspberry Pi Pico / Pico 2）

### 3.1 ピン割り当て（最終）

| GPIO | Pico ピン | ネット名 | つながる先 | 備考 |
|---|---|---|---|---|
| GP0 | 1 | BUZZER | R18 100Ω → 圧電ブザー | PWM0A |
| GP1 | 2 | SENS_LED_EN | R15 1kΩ → Q1 ベース | 1 で赤外LED 6 個点灯 |
| GP2, GP3 | 4, 5 | — | 未使用 | |
| GP4 | 6 | I2C_SDA | J2-4 | I2C0 |
| GP5 | 7 | I2C_SCL | J2-3 | I2C0 |
| GP6〜GP9 | 9〜12 | — | 未使用 | |
| GP10 | 14 | EXT_GP10 | J3-6 | 予備デジタル |
| GP11 | 15 | MOT_STBY | U3 STBY | 0 でドライバ待機（出力OFF）。ISD 復帰に使う |
| GP12 | 16 | MOT_IN1 | U3 IN1 | **左**モーター、PWM6A |
| GP13 | 17 | MOT_IN2 | U3 IN2 | **左**モーター、PWM6B |
| GP14 | 19 | MOT_IN3 | U3 IN3 | **右**モーター、PWM7A |
| GP15 | 20 | MOT_IN4 | U3 IN4 | **右**モーター、PWM7B |
| GP16 | 21 | SW1 | スタートボタン | 内部プルアップ、押すと 0 |
| GP17 | 22 | SW2 | セレクトボタン | 同上 |
| GP18 | 24 | LED1 | 赤 LED（1kΩ） | |
| GP19 | 25 | LED2 | 黄 LED（1kΩ） | |
| GP20 | 26 | MUX_S0 | U2 A (11番) | チャンネル番号の bit0 |
| GP21 | 27 | MUX_S1 | U2 B (10番) | bit1 |
| GP22 | 29 | MUX_S2 | U2 C (9番) | bit2 |
| GP26 / ADC0 | 31 | SENS_A | U2 COM (3番) | センサー値 |
| GP27 / ADC1 | 32 | VBAT_SENSE | R13/R14 分圧 | 電池電圧 = 読み値 × 2 |
| GP28 / ADC2 | 34 | EXT_A2 | J3-5 | 予備アナログ |
| GP25 | — | — | Pico 上の LED | Pico W / Pico 2 W では別ピン（無線チップ側） |
| GP29 / ADC3 | — | — | Pico 内部で VSYS/3 | 電源電圧の確認用 |

ピンの選び方の理由:
- **PWM のスライス**: 1 つのモーターの IN 2 本を同じスライスの A/B チャンネル（GP12/13 = スライス6、GP14/15 = スライス7）にした。周波数が必ず同じになり、ブレーキ駆動（後述）がしやすい。ブザー（GP0 = スライス0）とぶつからない。
- **基板上の位置**: Pico を USB 左向きに置いたとき、ADC と MUX 制御は前側の列、モーター制御は後ろ側の列の右端（モジュールの真横）、ボタン・LED は前側の列の右端（右前の角）に来るように選んだ。配線が短く交差が少ない。
- **Pico 2（RP2350）の注意（エラッタ E9）**: 入力ピンで内部プルダウンを使うと電圧が約 2 V に張り付くことがある。この基板は内部**プルダウンを使わない**設計（ボタンはプルアップ、ほかは出力か外部抵抗あり）なので Pico 2 でも問題ない。

### 3.2 Pico の載せ方

- 2.54 mm ピンヘッダ（1×20 ×2）を Pico と基板の両方にはんだ付け（いちばん安い）。
- 予算に余裕があれば、基板側をピンソケット（1×20 メス ×2、約 ¥80）にすると **Pico を外して再利用**できる。フットプリントは同じ。

---

## 4. モータードライバ（秋月 AE-TC78H653FTG）

### 4.1 モジュールのピン（DIP16 と同じ並び、上から見て）

```
          ┌──∪──┐
 LARGE  1 │      │ 16 VM
 MODE   2 │      │ 15 VM
 STBY   3 │ U3   │ 14 OUT4  ┐右モーター M2
 IN4    4 │      │ 13 OUT3  ┘
 IN3    5 │      │ 12 OUT1  ┐左モーター M1
 IN1    6 │      │ 11 OUT2  ┘
 IN2    7 │      │ 10 GND
 GND    8 │      │  9 GND
          └──────┘
```

### 4.2 設定

| ピン | 接続 | 意味 |
|---|---|---|
| LARGE | GND | スモールモード（2 モーター、1ch あたり 2 A DC / 2.5 A 10ms、ON 抵抗 0.22 Ω） |
| MODE | GND | IN 入力モード（IN1/IN2 で正転・逆転・ブレーキ・ストップ） |
| STBY | GP11 | 1 = 動作、0 = 待機（消費 0 µA）。**過電流検出(ISD)で止まったら、STBY を 0→1 にしないと復帰しない** |

入力は内部で 150 kΩ プルダウンされている → Pico が起動するまで（ピンが入力のまま）は自動的に「待機・停止」になり、電源投入時に暴走しない。
入力の H レベルは VM=3V で 1.7 V 以上、VM=5V で 2.0 V 以上 → Pico の 3.3 V 出力で OK。

### 4.3 真理値表（スモールモード・IN モード）

| IN1 | IN2 | OUT1 | OUT2 | 動作 |
|-----|-----|---|---|---|
| H | L | H | L | 正転 |
| L | H | L | H | 逆転 |
| H | H | L | L | ショートブレーキ |
| L | L | OFF | OFF | ストップ（空転） |

（IN3/IN4 と OUT3/OUT4 も同じ）

### 4.4 PWM のかけ方（ソフト側）

- **ブレーキ駆動（スローディケイ、標準）**: 正転なら IN1 = 常に H、IN2 = (1−デューティ) の PWM。OFF の間はショートブレーキになるので、速度がデューティに比例しやすく、減速も速い。ライントレーサー向き。
- **空転駆動（ファストディケイ）**: 正転なら IN1 = PWM、IN2 = L。OFF の間は空転。なめらかだがブレーキが効かない。
- PWM 周波数は 20 kHz（耳に聞こえない。データシート上限 500 kHz）。

### 4.5 過電流検出（ISD）の値（データシート p.9、参考値）

| VM | スモールモードの ISD しきい値 |
|----|---|
| 3.0 V | 約 2.0〜2.3 A |
| 4.0 V | 約 2.8〜3.0 A |
| 5.0 V | 約 3.3〜3.6 A |

モーターを止まった状態から 4.5 V 全開にすると 3 A 以上流れて ISD が働く。**ソフトスタートと電圧上限で防ぎ、万一のときは STBY で復帰**（`firmware/` に実装）。

---

## 5. ラインセンサー

### 5.1 1 チャンネル分の回路

```
 +3V3 ── R(100Ω) ──► IR-LED(A→K) ── LED_K ──[Q1 C-E]── GND      ← Q1 は 6 個共通
 +3V3 ── R(10kΩ) ──┬── SENSn → MUX
                   └── フォトTr (C→E) ── GND
```

| 項目 | 値 | 計算 |
|---|----|---|
| LED 電流 | 約 19 mA | (3.3 − 1.25 − 0.1) / 100 Ω |
| 6 個合計 | 約 115 mA | Q1 2SC1815（最大 150 mA）で ON/OFF。ベース電流 2.5 mA = (3.3−0.75)/1kΩ |
| 3V3 の負荷 | 約 150 mA | Pico の 3V3 出力は 300 mA まで推奨 |
| 出力電圧 | 白: 低い（約 1〜2 V）／黒: 高い（約 3 V） | 光が多いほどフォトTr に電流が流れて電圧が下がる |
| 応答 | LED を切り替えてから 0.2〜0.5 ms 待つ | 10 kΩ 負荷で数十〜100 µs |

- **外乱光キャンセル**: LED を消して読んだ値 − 点けて読んだ値 = 反射光だけの成分（窓からの日光などを打ち消す）。
- センサーの高さ（レンズと床）は 2〜3 mm が目安。読み値の差（白と黒）が小さい場合は R(10kΩ) を 22kΩ に上げると感度が上がる。

### 5.2 アナログマルチプレクサ（TC4051BP）

- 4000 シリーズの 8ch アナログスイッチ（DIP16、¥15）。VDD = 3.3 V で ON 抵抗は 1 kΩ 程度だが、センサー側が 10 kΩ・ADC 側は高インピーダンスなので問題なし。
- INH = GND（常に有効）、VEE = VSS = GND。
- **チャンネル割り当て（基板の配線をきれいにするため番号順ではない）**

| センサー（左→右） | S1 | S2 | S3 | S4 | S5 | S6 | J3 拡張1 | J3 拡張2 |
|---|----|----|----|----|----|----|----|----|
| MUX チャンネル | **4** | **2** | **1** | **0** | **3** | **5** | 6 | 7 |

→ ファームウェアでは `SENSOR_CH = [4, 2, 1, 0, 3, 5]`。

---

## 6. ボタン・LED・ブザー・拡張

| 部品 | 接続 | 備考 |
|---|---|---|
| SW1（スタート） | GP16 ─ SW ─ GND | 内部プルアップ使用、押すと 0 |
| SW2（セレクト） | GP17 ─ SW ─ GND | モード・速度の切り替えなど |
| LED1（赤）/ LED2（黄） | GP18/GP19 ─ 1kΩ ─ LED ─ GND | 約 1.3 mA（見える明るさ） |
| BZ1（圧電、オプション） | GP0 ─ 100Ω ─ ブザー ─ GND | 13 mm パッシブ型 PKM13EPYH4000-A0（秋月 104118、ピン間隔 5.0 mm）。12 mm・7.6 mm 間隔の物も挿せる（rev.A1 で穴を追加）。PWM で音階が出せる |
| J2（I2C） | GND, 3V3, SCL, SDA | **0.96 インチ OLED（SSD1306）と同じ並び** なのでそのまま差せる |
| J3（EXT 2×3） | 1 GND, 2 3V3, 3 X6, 4 X7, 5 GP28/ADC2, 6 GP10 | 追加センサー 2 個（マーカー検出など）や予備ピン |

---

## 7. ノイズ対策

- モーター端子に 0.1 µF（C5, C6）。さらに効かせたい場合は **モーター本体の端子間にも 0.1 µF** をはんだ付けする（ミニ四駆と同じ）。
- 基板は 2 層とも GND ベタ。アナログ線（センサー → MUX → GP26）は基板の前側に集め、モーター電流の流れる後ろ側（モジュール → モーター端子）と分けた。
- 電池からモジュールまで（VBAT）とモーター線（MOT_OUT）は 1.0 mm 幅、3.3V/VSYS は 0.6 mm 幅。

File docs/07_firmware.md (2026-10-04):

# 07. ソフトウェア（MicroPython）

> ファイル: `firmware/micropython/`
> - `linetracer.py` … ライブラリ（ピン番号・モーター・センサー・ブザー）。**基板を変えたらここを直す**
> - `main.py` … 標準プログラム（PD 制御のライントレース）
> - `examples/01〜05` … 授業用の段階別サンプル

---

## 1. 準備（はじめの 1 回）

1. **MicroPython を書き込む**
   - https://micropython.org/download/ から、使うボードに合った `.uf2` をダウンロード
     （Raspberry Pi Pico → `RPI_PICO`、Pico 2 → `RPI_PICO2`、Pico W → `RPI_PICO_W`）
   - Pico の **BOOTSEL ボタンを押しながら** USB をつなぐ → `RPI-RP2`（Pico 2 は `RP2350`）というドライブが出る → `.uf2` をコピー
2. **Thonny**（https://thonny.org/）をインストール → 右下のインタプリタを「MicroPython (Raspberry Pi Pico)」に
3. `linetracer.py` と `main.py` を Pico に保存（Thonny の「ファイル」→「名前を付けて保存」→「Raspberry Pi Pico」）
   - `main.py` という名前のファイルは、電源を入れると自動で動く

## 2. 授業の流れ（例）

| 回 | サンプル | 学ぶこと |
|----|---|---|
| 1 | `01_led_blink.py` | 出力、`time.sleep` |
| 2 | `02_buttons_buzzer.py` | 入力（プルアップ）、`if`、PWM で音 |
| 3 | `03_sensor_monitor.py` | アナログ値、白と黒の違い、Thonny のプロッター |
| 4 | `04_motor_test.py` | モーターの前進・後退・旋回（車輪を浮かせて） |
| 5 | `05_simple_tracer.py` | ON/OFF 制御のライントレース（2 センサー） |
| 6 | `main.py` | 6 センサーで線の位置を計算 → P 制御 → PD 制御、速さの調整 |

## 3. ライブラリの使い方

```python
from linetracer import Robot
robot = Robot()

robot.motors.run(30, 30)        # 左 30%、右 30%（100% = 3.0V）。マイナスで後退
robot.motors.brake()            # ブレーキ
robot.motors.stop()             # 空転（力を抜く）

robot.sensors.calibrate()       # 呼ぶたびに白と黒を覚える（線の上で左右に動かす）
robot.auto_calibrate()          # その場で左右に回って自動キャリブレーション
v = robot.sensors.read()        # [S1..S6] 0(白)〜1000(黒)
pos = robot.sensors.position()  # 線の位置 -2500(左端)〜0(真ん中)〜+2500(右端)、見失うと None

robot.start_pressed()           # START が押されていれば True
robot.led1.value(1)             # LED1 点灯
robot.buzzer.beep(2)            # ピピッ
robot.battery.read()            # 電池電圧 [V]
```

### 3.1 モーターまわりの安全機能（子どもが知らなくても動く）

| 機能 | しくみ |
|---|---|
| 電圧上限 | `run(100, 100)` でもモーターには 3.0 V（`MAX_MOTOR_VOLT`）までしかかからないよう、**電池電圧を測ってデューティを自動計算**。電池が減っても同じ % なら同じ速さ |
| ソフトスタート | `run()` 1 回あたりデューティは最大 4% しか変えない（`RAMP_PER_CALL`）。急発進でドライバの過電流保護が働くのを防ぐ |
| ISD 自動復帰 | 走行中は 0.1 秒ごとに STBY を一瞬 L→H にして、過電流で止まった出力を復帰させる |
| ブレーキ駆動 | PWM の OFF 時間はショートブレーキ（速度がデューティに比例しやすい） |
| 起動時は停止 | Pico が起動するまでドライバの入力は内部プルダウンで L → モーターは回らない |

### 3.2 センサーの読み方（外乱光キャンセル）

1. 赤外 LED を点灯 → 0.3 ms 待つ → 6 個読む
2. LED を消灯 → 0.3 ms 待つ → 6 個読む
3. 「消灯の値 − 点灯の値」= 反射光だけの強さ（窓からの光などを打ち消す）

1 回の読み取りは約 1 ms。`robot.sensors.ambient_cancel = False` にすると速くなる（点灯のみ）。

MUX のチャンネルは配線の都合でセンサー順と違う（`SENSOR_CH = (4, 2, 1, 0, 3, 5)`）。ライブラリの中で並べ替えているので、使う側は S1〜S6 の順で考えればよい。

## 4. PD 制御（`main.py`）

```
誤差 e   = 線の位置（-2500〜+2500）
操作量 u = Kp × e + Kd × (e の変化 / ミリ秒)
左モーター = 基本速度 + u
右モーター = 基本速度 − u
```

| レベル | 基本速度 | Kp | Kd |
|---|---|----|----|
| 1（遅い） | 30% | 0.012 | 0.35 |
| 2 | 45% | 0.016 | 0.50 |
| 3（速い） | 60% | 0.020 | 0.65 |

**これらは計算上の初期値**。実機で必ず調整する:

1. Kd = 0 にして Kp を少しずつ上げる → 線の上でジグザグ（蛇行）し始める少し手前の値にする
2. Kd を上げて蛇行を止める（上げすぎるとガタガタ震える）
3. 基本速度を上げる → カーブで外れたら Kp・Kd を上げ直す

線を見失ったら、最後に見えた側へ強く曲がり、0.8 秒見つからなければ止まる。

## 5. ピン番号を変えたいとき

`linetracer.py` の先頭の `PIN_…` を書き換えるだけ。基板（rev.A）の配線は `03_circuit.md` の表のとおり。

## 6. よくある質問

- **Q. モーターが回らない** → 電池ボックスのスイッチ、`robot.battery.read()` が 3V 以上か。USB だけではモーターは回らない（仕様）。
- **Q. 左右どちらかが逆に回る** → `LEFT_INVERT` / `RIGHT_INVERT` を変える。
- **Q. 走るとすぐ止まる・リセットする** → 電池が弱い。`MAX_MOTOR_VOLT` を 2.5 にする、ソフトスタートを強める（`RAMP_PER_CALL = 0.02`）。
- **Q. Pico W / Pico 2 W を使いたい** → そのまま動く。ただし基板上の Pico の LED は GP25 ではない（`Pin("LED")` を使う）。
- **Q. C/C++（Arduino）で書きたい** → Arduino-Pico（earlephilhower 版）で同じピン番号を使えば OK。PWM は `analogWriteFreq(20000)`、`analogWriteRange(65535)`。

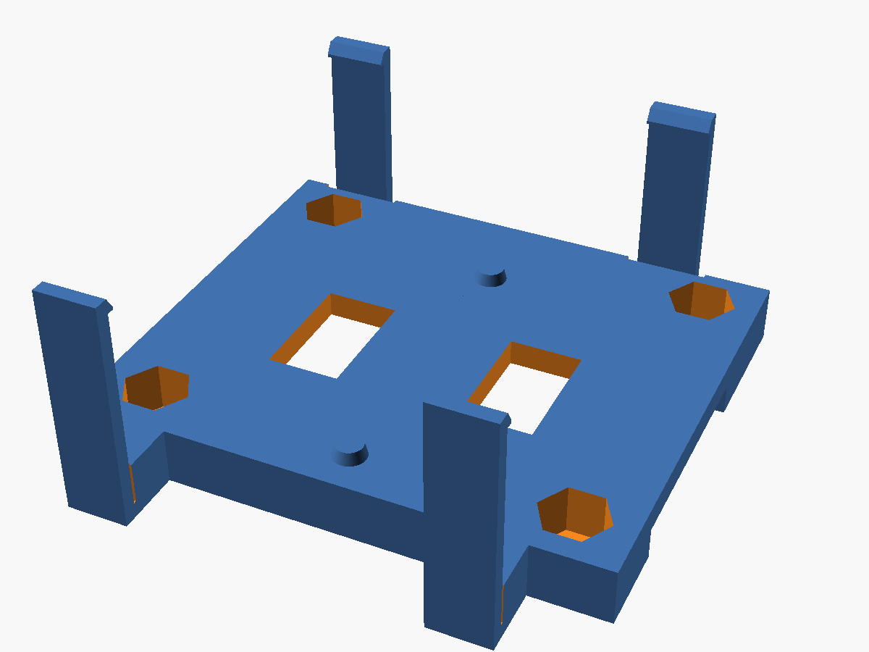
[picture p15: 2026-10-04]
hardware/mechanical/deck_clip.png

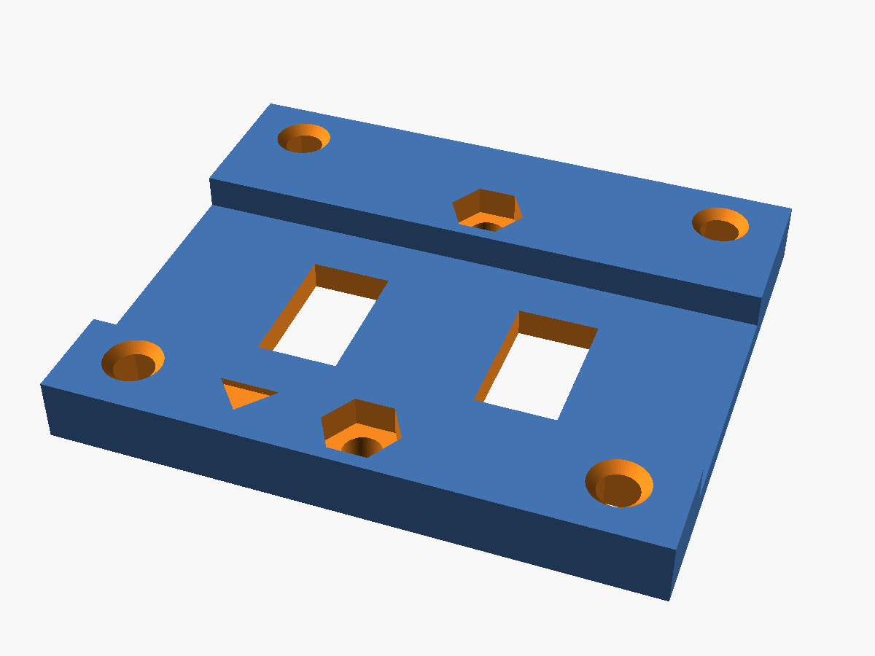
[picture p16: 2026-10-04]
hardware/mechanical/deck.png

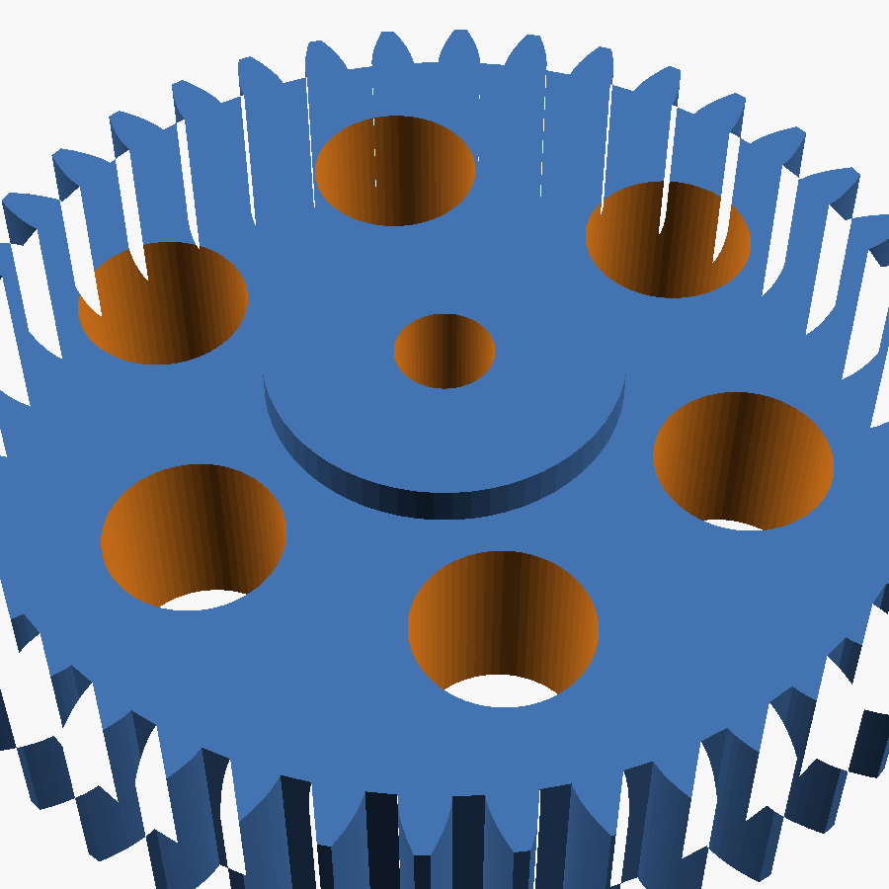
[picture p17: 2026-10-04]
hardware/mechanical/gear40.png

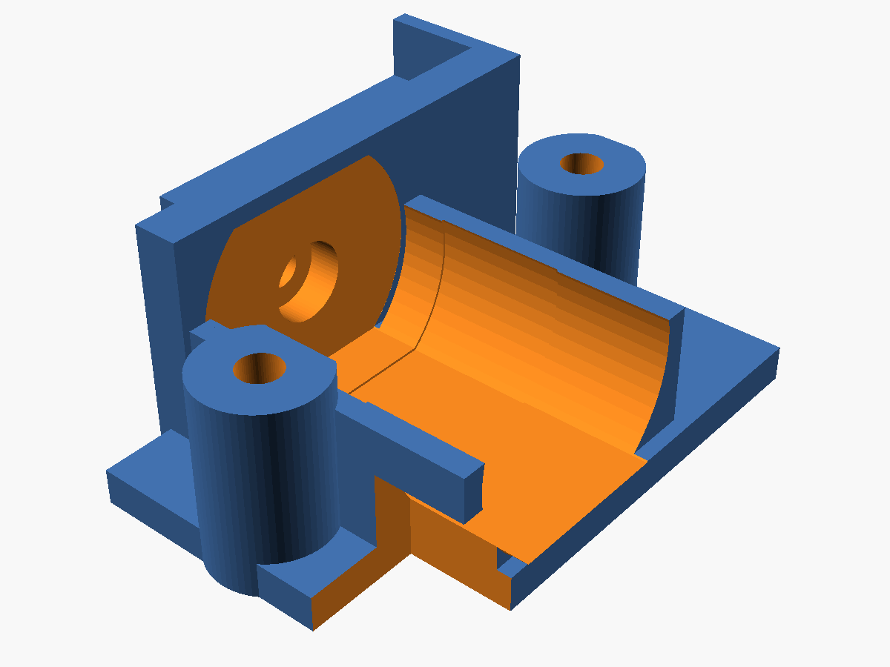
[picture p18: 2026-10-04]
hardware/mechanical/frame_left.png

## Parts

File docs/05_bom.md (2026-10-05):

# 05. 部品表（BOM）・買い方・コスト

> 最終更新: 2026-10-05（rev.A1）
> 秋月の価格・通販コードは 2026-10-05 にサイトで確認（✔）。≒ は目安（店・時期で変わる）。
> KiCad から書き出した機械可読の部品表: `hardware/kicad/bom/Linetracer2_bom.csv`（秋月の通販コード入り）

---

## 0. 買い方のルール（サークルの方針）

| ルール | 理由・やり方 |
|---|---|
| **実店舗で売っている物、または T 番号（適格請求書発行事業者の登録番号）のある通販で買える物だけ使う** | 大学の会計で精算できるように、**適格請求書（T 番号入りの領収書・請求書）** を必ずもらう |
| 通販は **秋月電子通商**（店頭・通販）、**Amazon**（下の注意）、モノタロウ、ヨドバシなど | どこも T 番号入りの領収書を出せる。T 番号は [国税庁 適格請求書発行事業者公表サイト](https://www.invoice-kohyo.nta.go.jp/) で確認できる |
| Amazon は **「Amazon.co.jp が販売・発送」または出品者が適格請求書発行事業者** のものだけ | マーケットプレイスの無名品は T 番号が無いことがあり、在庫も安定しない。**ブランド品（タミヤ・光など）を選ぶ** |
| 海外通販（AliExpress 等）・ノーブランド品は使わない | 精算できない／同じ物が二度と買えないことがある |
| 3D プリント部品はサークルの **Bambu Lab P1S** で作る | 材料はフィラメントだけ（ヨドバシ・Amazon で買える） |

> 例外: **基板（PCB）は特注品**なので店では売っていない（[§4](#4-基板の発注)）。

---

## 1. 基板に載る部品（すべて足付き＝リード部品、ぜんぶ秋月で買える）

| 記号 | 部品 | 数 | 秋月 通販コード | 単価 | 小計 | 備考 |
|---|---|----|---|---|---|---|
| U1 | Raspberry Pi Pico | 1 | 116132 ✔ | ¥800 | ¥800 | Pico 2（¥990）・Pico W も同じ形で可 |
| — | ピンヘッダ 1×40 | 1 | 100167 ✔ | ¥35 | ¥35 | 20 ピンずつに折って Pico 用 |
| U3 | モータードライバーモジュール AE-TC78H653FTG | 1 | 114746 ✔ | ¥200 | ¥200 | 1×8 ピンヘッダ 2 本付属 |
| U2 | TC4051BP（8ch アナログマルチプレクサ） | 1 | 110914 ✔ | ¥15 | ¥15 | DIP16。IC ソケット 16P を使うと安心（任意） |
| PS1〜PS6 | フォトリフレクタ LBR-123F | 6 | 116455 ✔ | ¥40 | ¥240 | **基板の裏面**に付ける（在庫 1 万個以上） |
| Q1 | トランジスタ 2SC1815-GR | 1 | 117089 ✔（20 個 ¥100） | ¥5 | ¥5 | |
| D1 | ショットキーダイオード 1N5819 | 1 | 117244 ✔（10 個 ¥100） | ¥10 | ¥10 | 帯（カソード）の向きに注意 |
| R1〜R6, R18 | 抵抗 100Ω 1/4W（茶黒茶） | 7 | 125101 ✔（100 本 ¥200） | ¥2 | ¥14 | |
| R7〜R14 | 抵抗 10kΩ 1/4W（茶黒橙） | 8 | 125103 ✔（100 本 ¥100） | ¥1 | ¥8 | |
| R15〜R17, R19 | 抵抗 1kΩ 1/4W（茶黒赤） | 4 | 125102 ✔（100 本 ¥100） | ¥1 | ¥4 | |
| C1, C2 | 電解コンデンサ 470µF 16V（φ8×9, ピッチ 3.5） | 2 | 108426 ✔ | ¥10 | ¥20 | Rubycon 16WXA。＋−の向きに注意 |
| C3〜C6 | 積層セラミック 0.1µF 50V（2.54mm） | 4 | 113582 ✔（10 個 ¥100） | ¥10 | ¥40 | |
| D4 | LED 3mm **黄緑**（電源） | 1 | 111637 ✔ | ¥10 | ¥10 | ※ 525nm の「緑」は Vf が約 3V で 3.3V では暗いので不可 |
| D2 | LED 3mm 赤 | 1 | 111577 ✔ | ¥10 | ¥10 | 長い足が＋ |
| D3 | LED 3mm 黄 | 1 | 111639 ✔ | ¥20 | ¥20 | |
| SW1, SW2 | タクトスイッチ 6mm | 2 | 108075 ✔ | ¥10 | ¥20 | |
| J1 | XH コネクタ ベース付ポスト 2P（B2B-XH-A） | 1 | 112247 ✔ | ¥10 | ¥10 | 電池ボックス用 |
| BZ1 | 圧電スピーカー 13mm PKM13EPYH4000-A0 | (1) | 104118 ✔ | ¥30 | (¥30) | **オプション**。基板の **「+」と「13」の穴**に差す（rev.A1 で追加した穴） |
| J2, J3 | ピンヘッダ（I2C 1×4、EXT 2×3） | — | （100167 の余り） | — | — | **付けなくてよい**（発展課題用） |
| | | | | | **¥1,461** | 基板代・ブザーは別 |

## 2. 機械部品

| 部品 | 数 | 買う所 | 単価 | 小計 | 備考 |
|---|----|---|---|---|---|
| DC モーター FA-130RA-2270 | 2 | 秋月 106437 ✔ | ¥150 | ¥300 | |
| 電池ボックス 単3×3本 スイッチ・XH コネクター付（BH-331-3ASTH-150MM） | 1 | 秋月 112243 ✔ | ¥130 | ¥130 | 底にある 2 つの皿穴でデッキにねじ止め |
| ピニオンギヤ 8T（m0.5、φ2 軸） | 2 | **タミヤ ミニ四駆 GP No.289「8T ピニオンギヤ（真ちゅう・プラ 各 4 個）」15289**（定価 ¥308）✔ | ¥39 | ¥77 | 模型店・ヨドバシ・Amazon（Amazon.co.jp 販売）。1 袋で 4 台分（真ちゅう優先） |
| 平歯車 40T（m0.5） | 2 | **3D プリント**（`gear40.stl`） | — | — | 予備案: 小原歯車 DS0.5-40（モノタロウ・ミスミ、1 個 ¥300 前後、寸法は要確認） |
| 車軸 真鍮丸棒 φ2mm × 20mm | 2 | ホームセンター（光 HIKARI「真鍮丸棒 2mm」約 1m） | ≒¥7 | ≒¥15 | **先生が金のこで切って、切り口をやすりで丸めておく**（1m で約 45 本） |
| O リング P-24（NBR、内径 23.7、太さ 3.5） | 2 | カインズ（ESCO EA423RB-24、10 個入、店舗受取）／モノタロウ | ≒¥40 | ≒¥80 | タイヤ。TPU を持っていれば `tire_tpu.stl` を印刷してもよい |
| 3D プリント部品 一式 | 1 式 | P1S で印刷（PLA 約 30 g） | — | ≒¥90 | 枠 L/R、デッキ、平歯車 ×2、車輪 ×2、スキッド（ツメで差し込む）（`hardware/mechanical/`） |
| なべ小ねじ M3×20 | 4 | ホームセンター／秋月 107437 ✔（10 本 ¥320） | ≒¥15 | ≒¥60 | 基板 → 枠 → デッキを一緒に締める |
| 皿小ねじ M3×8 | 2 | ホームセンター | ≒¥10 | ≒¥20 | 電池ボックス。**ツメ版デッキなら不要**（ナットも 4 個でよい） |
| 六角ナット M3（鉄） | 6 | ホームセンター／秋月 114372 ✔（10 個 ¥120） | ≒¥8 | ≒¥50 | デッキの六角穴に埋める |
| モーター用の電線（AWG24〜26、6cm × 4 本） | 少々 | 秋月・ホームセンター | | ≒¥10 | 赤・黒 |
| | | | | **≒¥832** | |

> **テープ・接着剤は使わない。** 機械部品は M3 ねじ（長さ 2 種類）と、3D プリントのツメ（スキッド、任意で電池ボックス）で固定する。
> スキッドをツメ式にしたので、rev.A1 初版にあったナイロンナット（買いにくい）は不要になった（ねじ版スキッドを使うときだけ必要）。

## 3. 合計と ¥1,500 について

| 構成（1 台） | 合計 | 内訳 |
|---|---|---|
| **A. 全部新品（純正 Pico 込み、基板 ¥80、ブザー別）** | **約 ¥2,370** | 電子 ¥1,461 ＋ 基板 ¥80 ＋ 機械 ≒¥832 |
| **B. Pico を講座で再利用（貸し出し）する** | **約 ¥1,540** | A から Pico ＋ ピンヘッダ（¥835）を除く |
| B ＋ まとめ買いの工夫 | 約 ¥1,440〜1,500 | ねじ・ナットを徳用袋、O リング・フィラメントを安い銘柄で（−¥100 程度）。ツメ版デッキならさらに −¥30 |

- **純正 Pico だけで ¥800（全体の約 1/3）**。以前の案（海外通販の Pico 互換ボード・互換モーター）は「T 番号のある店だけ」のルールで使えなくなったので、**¥1,500 に近づけるには「Pico を再利用」が現実的な唯一の方法**。
- 価格が大きいもの: Pico ¥800、センサー 6 個 ¥240、モーター 2 個 ¥300、ドライバ ¥200。センサーを 4 個に減らすと −¥80 だが、性能（位置の分解能）が落ちるのでおすすめしない。
- 部品は授業の台数ぶんまとめて買うと、抵抗・コンデンサ・ねじの袋の余りが減る（下の §5）。
- **さらに安くしたい場合は低コスト版 Lite**（`../lite/README.md`）: Pico 直付け・センサー 3 個・ボタン 1 個・LED 1 個・ブザーなし・TPU タイヤで **約 ¥2,060（−¥310）**。ただし Pico ははんだ付けするので再利用（B 案）はできない。

## 4. 基板の発注

- 基板は特注品なので**店頭販売は無い**。Gerber: `hardware/Linetracer2_rev.A1_gerber.zip`、仕様と手順は `04_pcb.md` §5。
- **JLCPCB（中国）** が最安（30 枚で 1 枚 ¥40〜100 程度＋送料）だが海外の業者。**大学の会計で精算できるか事前に確認**すること（日本の T 番号入り請求書は出ない前提で考える）。
- 精算の都合で国内業者が必要なら、P板.com などの国内の基板製造サービスに同じ Gerber で見積りを取る（1 枚あたりは JLCPCB より高い）。

## 5. 授業 10 台分の買い物リスト（例）

| 店 | 品物（通販コード） | 数 |
|----|---|----|
| 秋月 | Pico 116132 ×10、ピンヘッダ 100167 ×10、AE-TC78H653FTG 114746 ×10、TC4051BP 110914 ×10、LBR-123F 116455 ×60、2SC1815 117089 ×1 袋、1N5819 117244 ×1 袋、抵抗 125101 ×1、125103 ×1、125102 ×1 袋、470µF 108426 ×20、0.1µF 113582 ×4 袋、LED 111637 ×10・111577 ×10・111639 ×10、タクトスイッチ 108075 ×20、XH ポスト 112247 ×10、電池ボックス 112243 ×10、FA-130RA 106437 ×20、（ブザー 104118 ×10） | |
| 模型店・ヨドバシ・Amazon | タミヤ 15289 ×3 袋（真ちゅうのピニオンだけ使うなら ×5 袋） | |
| ホームセンター | 真鍮丸棒 φ2 ×1 本、なべ小ねじ M3×20 ×40、皿小ねじ M3×8 ×20、六角ナット M3 ×60、（電線） | |
| カインズ（店舗受取）／モノタロウ | O リング P-24 ×2 袋（20 個） | |
| ヨドバシ・Amazon | PLA フィラメント（300 g 程度） | |

## 6. 1 台あたりのはんだ付け箇所（子どもの作業量の目安）

| 部品 | 箇所 |
|---|---|
| Pico（ヘッダ側 40 ＋ 基板側 40） | 80 |
| モーターモジュール（16 ＋ 16） | 32（モジュール側は先生がやってもよい） |
| 4051 | 16 |
| センサー 6 個 × 4 | 24 |
| 抵抗 19 本 × 2 | 38 |
| コンデンサ・LED・ダイオード・トランジスタ・スイッチ・コネクタ | 約 30 |
| モーター線（モーター側 4 ＋ 基板側 4） | 8 |
| **合計** | **約 230 箇所** |

→ 1 日（2〜3 時間 × 2 コマ）を想定。Pico とモジュールのヘッダは事前に先生側でつけておくと、子どもの作業は約 120 箇所に減る。

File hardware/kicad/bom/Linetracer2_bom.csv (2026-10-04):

Refs | Value | Footprint | Akizuki | Note | Qty
BZ1 | piezo (option) | Linetracer2:Buzzer_P5.0_P7.6 | 104118 (PKM13EPYH4000-A0) | passive piezo, optional. 13mm PKM13EPYH4000-A0 (pitch 5.0) or 12mm (pitch 7.6) | 1
C1,C2 | 470uF 16V | Capacitor_THT:CP_Radial_D8.0mm_P3.50mm | 108426 (Rubycon 16WXA470MEFC 8x9) | hold-up for Pico when motors pull the battery down,motor bulk capacitor, place near U3 VM | 2
C3,C4 | 0.1uF | Capacitor_THT:C_Disc_D3.0mm_W2.0mm_P2.50mm | 113582 (10pcs) |  | 2
C5,C6 | 0.1uF (at motor) | Capacitor_THT:C_Disc_D3.0mm_W2.0mm_P2.50mm | 113582 (10pcs) |  | 2
D1 | 1N5819 | Diode_THT:D_DO-41_SOD81_P10.16mm_Horizontal | 117244 | blocks USB 5V back-feed into batteries | 1
D2 | LED red | LED_THT:LED_D3.0mm | 111577 |  | 1
D3 | LED yellow | LED_THT:LED_D3.0mm | 111639 |  | 1
D4 | LED yellow-green (POWER) | LED_THT:LED_D3.0mm | 111637 |  | 1
J1 | BATTERY (AA x3, XH 2P) | Linetracer2:BatteryXH_2P | 112247 (B2B-XH-A) / battery box 112243 | red wire = + (pin 1) | 1
J2 | I2C (0.96in OLED order) | Connector_PinHeader_2.54mm:PinHeader_1x04_P2.54mm_Vertical |  |  | 1
J3 | EXT (2x3) | Connector_PinHeader_2.54mm:PinHeader_2x03_P2.54mm_Vertical |  |  | 1
M1 | LEFT motor FA-130RA | Linetracer2:MotorPads_2P_Relief | 106437 |  | 1
M2 | RIGHT motor FA-130RA | Linetracer2:MotorPads_2P_Relief | 106437 |  | 1
PS1-PS6 | LBR-123F | Linetracer2:LBR-123F | 116455 |  | 6
Q1 | 2SC1815-GR | Package_TO_SOT_THT:TO-92_Inline_Wide | 117089 |  | 1
R1-R6,R18 | 100 | Resistor_THT:R_Axial_DIN0207_L6.3mm_D2.5mm_P10.16mm_Horizontal | 125101 (100pcs) |  | 7
R7-R14 | 10k | Resistor_THT:R_Axial_DIN0207_L6.3mm_D2.5mm_P10.16mm_Horizontal | 125103 (100pcs) |  | 8
R15-R17,R19 | 1k | Resistor_THT:R_Axial_DIN0207_L6.3mm_D2.5mm_P10.16mm_Horizontal | 125102 (100pcs) |  | 4
SW1 | START | Button_Switch_THT:SW_PUSH_6mm | 108075 |  | 1
SW2 | SELECT | Button_Switch_THT:SW_PUSH_6mm | 108075 |  | 1
U1 | Raspberry Pi Pico | Module:RaspberryPi_Pico_Common_THT | 116132 (Pico, Pico 2 / Pico W also OK) |  | 1
U2 | TC4051BP (CD4051B) | Package_DIP:DIP-16_W7.62mm | 110914 |  | 1
U3 | AE-TC78H653FTG | Linetracer2:AE-TC78H653FTG | 114746 |  | 1

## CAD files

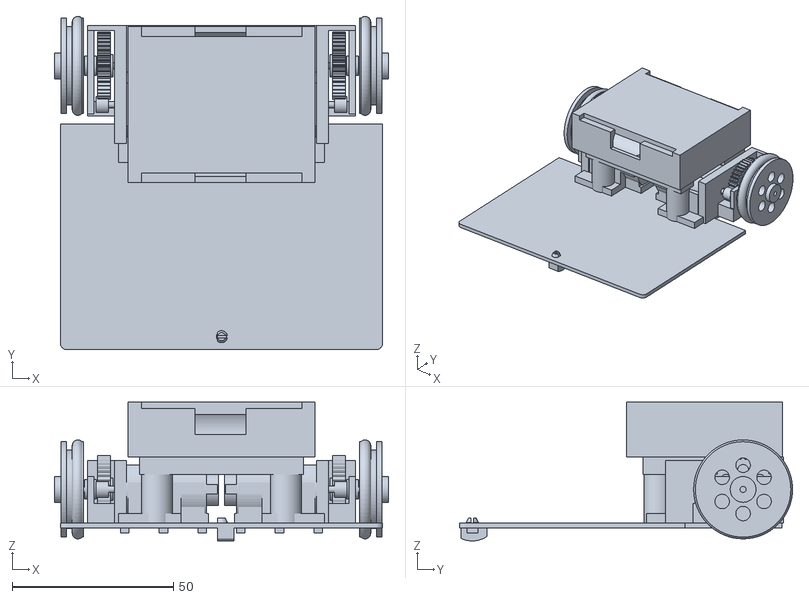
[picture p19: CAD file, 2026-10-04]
hardware/mechanical/assembly.stl
103.6 x 103.3 x 43.1

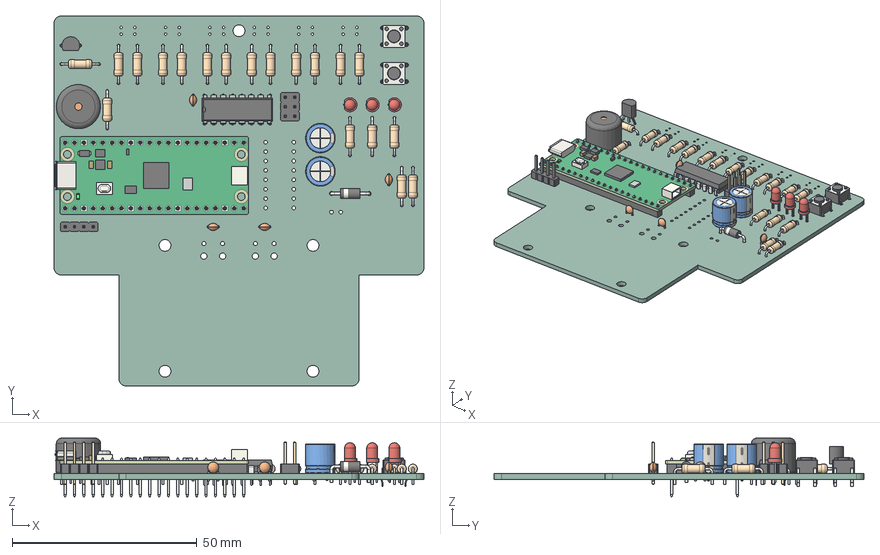
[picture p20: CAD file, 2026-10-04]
hardware/kicad/Linetracer2_pcb.step
100.0 x 100.0 x 15.9 mm
C_Disc_D30mm_W20mm_P250mm x 4
CP_Radial_D80mm_P350mm x 2
R_Axial_DIN0207_L63mm_D25mm_P1016mm_Horizontal x 19
SW_PUSH_6mm x 2
LED_D3.0mm x 3
D_DO-41_SOD81_P10.16mm_Horizontal
Buzzer_12x95RM76
PinHeader_1x04_P254mm_Vertical
TO-92_Inline_Wide
DIP-16_W7.62mm
PinHeader_2x03_P254mm_Vertical
RaspberryPi_Pico_H_Module_KiCad
RaspberryPi_Pico_Header_DIP-40_H2.54mm_KiCad
Linetracer2_PCB

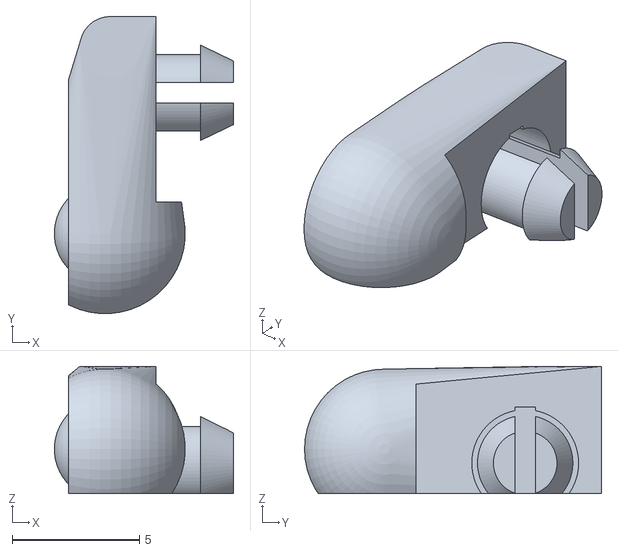
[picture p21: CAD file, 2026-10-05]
hardware/mechanical/caster_print_h40.stl
7.05 x 11.7 x 5.00

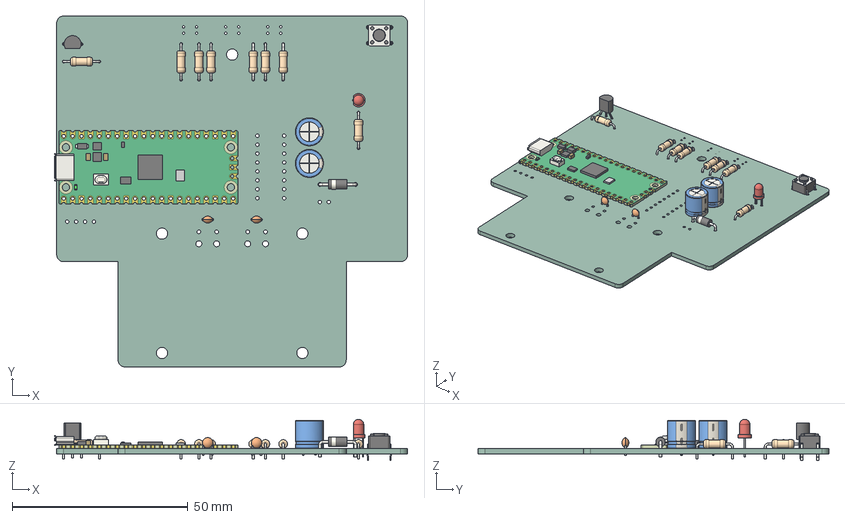
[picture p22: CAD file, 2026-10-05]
lite/hardware/kicad/Linetracer2-Lite_pcb.step
100.7 x 100.0 x 11.8 mm
R_Axial_DIN0207_L63mm_D25mm_P1016mm_Horizontal x 8
RaspberryPi_Pico_Module_KiCad
TO-92_Inline_Wide
LED_D3.0mm
C_Disc_D30mm_W20mm_P250mm x 2
CP_Radial_D80mm_P350mm x 2
D_DO-41_SOD81_P10.16mm_Horizontal
SW_PUSH_6mm
Linetracer2-Lite_PCB

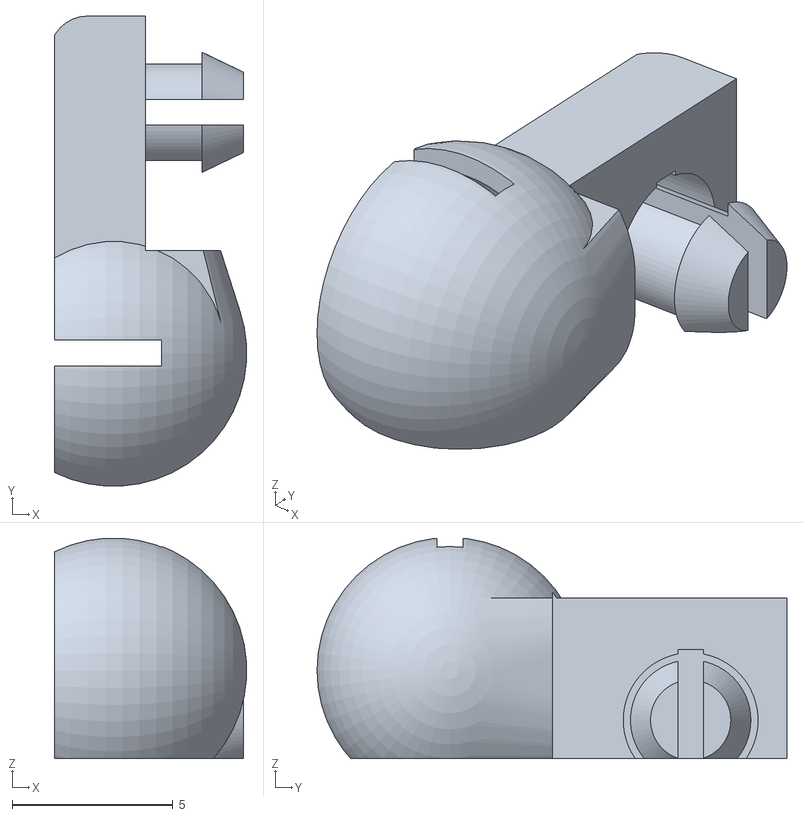
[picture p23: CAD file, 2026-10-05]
hardware/mechanical/caster_bead_h40.stl
5.98 x 14.6 x 6.86

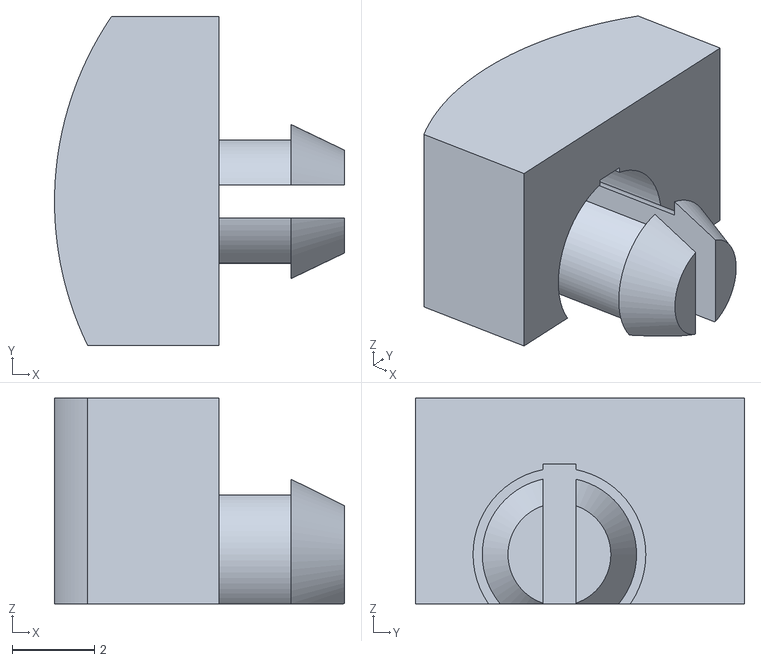
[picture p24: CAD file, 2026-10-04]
hardware/mechanical/skid_clip_h40.stl
7.05 x 8.00 x 5.00

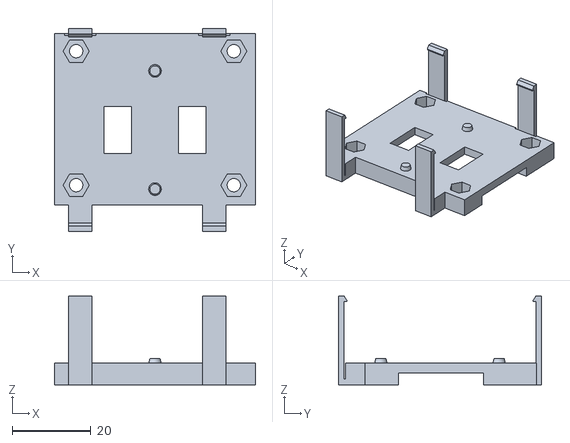
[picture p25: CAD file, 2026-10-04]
hardware/mechanical/deck_clip.stl
51.0 x 51.4 x 22.5

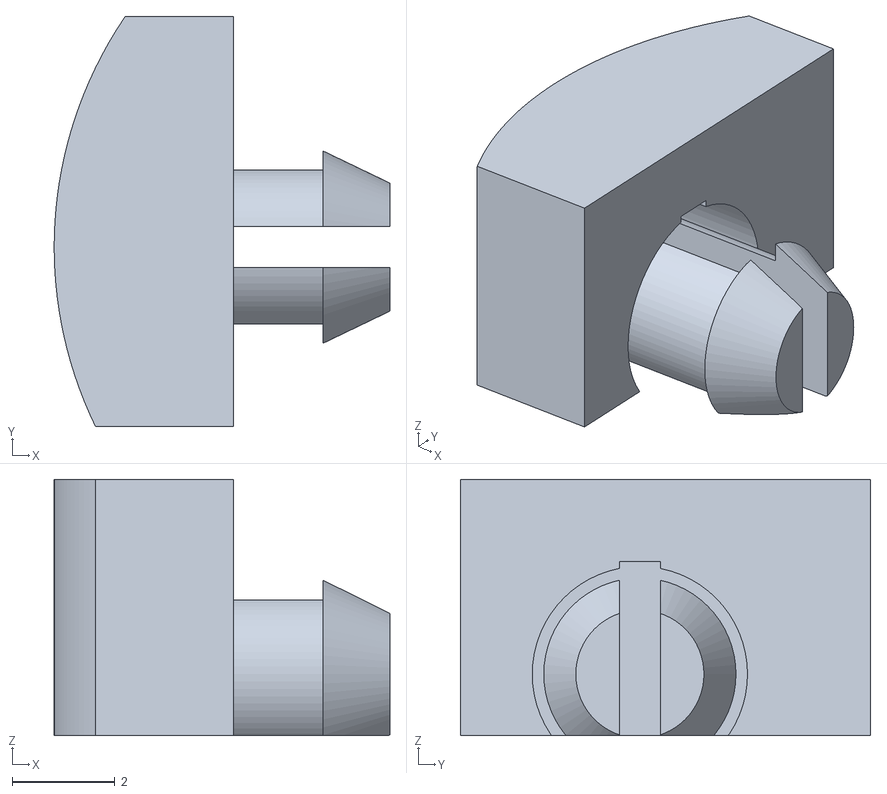
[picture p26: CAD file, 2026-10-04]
hardware/mechanical/skid_clip_h35.stl
6.55 x 8.00 x 5.00

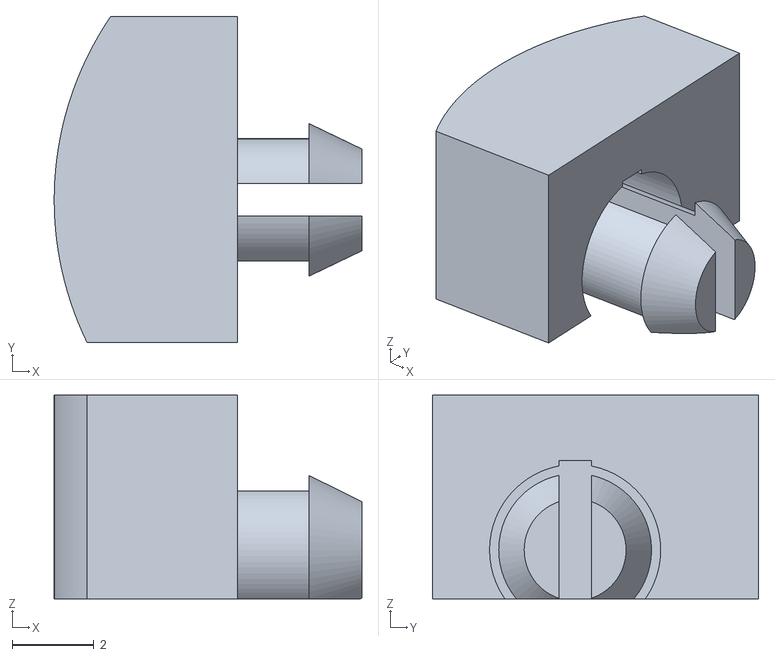
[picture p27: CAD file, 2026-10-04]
hardware/mechanical/skid_clip_h45.stl
7.55 x 8.00 x 5.00

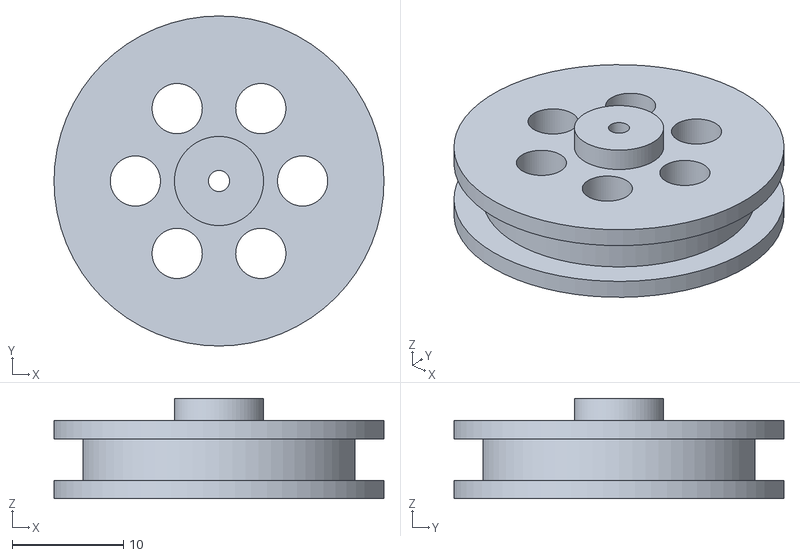
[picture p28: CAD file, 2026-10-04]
hardware/mechanical/wheel.stl
29.6 x 29.6 x 9.00

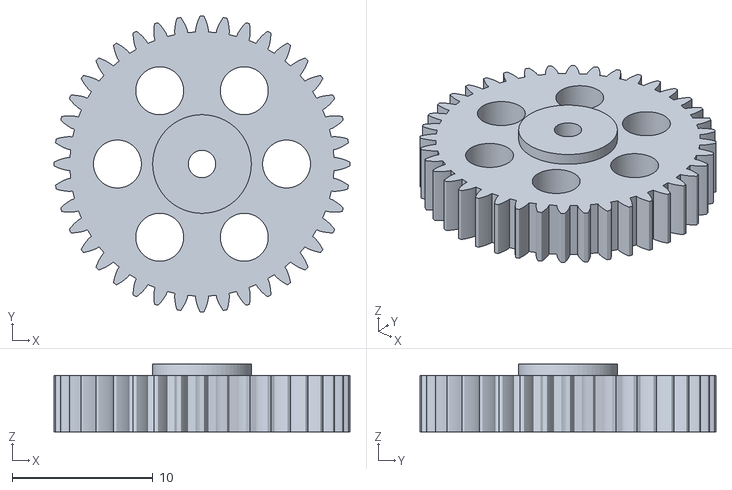
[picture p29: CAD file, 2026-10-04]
hardware/mechanical/gear40.stl
21.0 x 21.0 x 4.80

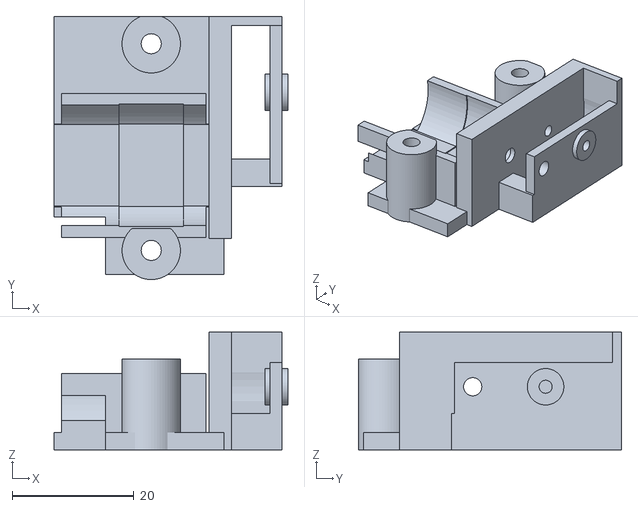
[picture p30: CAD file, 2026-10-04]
hardware/mechanical/frame_right.stl
38.5 x 43.3 x 19.4

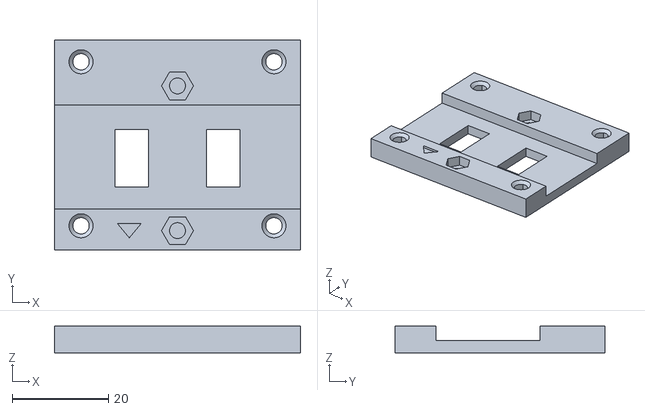
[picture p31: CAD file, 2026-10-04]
hardware/mechanical/deck.stl
51.0 x 43.5 x 5.50

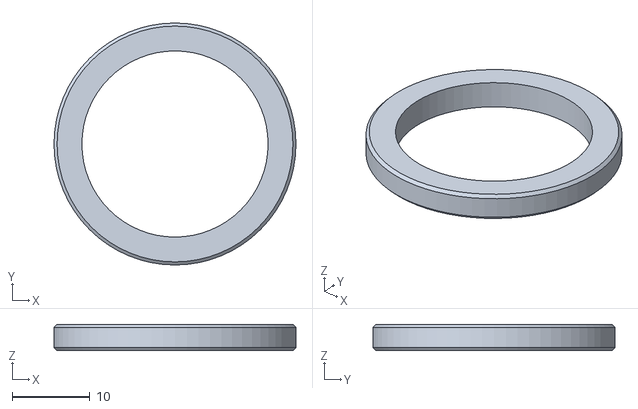
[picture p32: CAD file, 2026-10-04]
hardware/mechanical/tire_tpu.stl
31.2 x 31.2 x 3.40

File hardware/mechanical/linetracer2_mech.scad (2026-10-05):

// Linetracer2 - 3D printable mechanical parts (OpenSCAD 2021.01), rev.A1
//
//   part = "frame_left" | "frame_right" | "deck" | "gear40" | "wheel" | "tire_tpu" | "skid" | "skid_clip"
//        | "deck_clip" | "caster_print" | "caster_bead"
//        | "assembly" | "check_*" (interference checks, must be empty)
//   openscad -D 'part="frame_left"' -o frame_left.stl linetracer2_mech.scad
//
// Coordinates = PCB coordinates (mm): x -> right, y -> rear, z = 0 on the PCB TOP surface.
// (0,0) is the front-left corner of the board.  Floor is at z = -5.6 (PCB bottom 4.0 mm).
//
// Drive: FA-130RA + Tamiya 8T pinion (m0.5) -> printed 40T spur (m0.5) on a 2 mm axle, 5:1, wheel ~32 mm.
// Everything is held by screws (no tape):
//   4 x M3x20 pan  : from the PCB bottom, through the PCB and the frame towers, into nuts in the deck
//   2 x M3x8  flat : battery box floor -> deck (nuts in the deck)
//   1 x M3x8  flat : skid (from the floor side) -> NYLON nut on the PCB top (next to sensor solder joints)
//
// LITE = true : low-cost Lite board (3 sensors, skid at (50,11), printed TPU tyres instead of O-rings).
//   openscad -D 'LITE=true' -D 'part="check_skid_sensor"' ...   All printed parts are the same for both boards.

part = "assembly";
LITE = false;
$fn = 64;

// ---------------------------------------------------------------- parameters
PCB_T      = 1.6;
FLOOR_Z    = -5.6;          // floor relative to PCB top
AXLE_Y     = 88;            // must match gen_pcb.py
MOTOR_Y    = 76;            // motor shaft line (AXLE_Y - 12)
AXIS_Z     = 10.4;          // wheel radius 16 - 5.6
NOTCH_X    = 17.5;          // PCB edge in the rear notch (left side)
HOLES      = [[30, 62], [30, 96]];   // M3 holes (left frame); right frame = mirrored (70, ..)

// FA-130 (left motor): shaft points to -x
CAN_W = 20.1; CAN_H = 15.0; CAN_R = CAN_W / 2;
CAN_X0 = 20.5; CAN_X1 = 45.3;          // can front face .. rear face
BOSS_D = 6.0; BOSS_L = 1.7;            // front bearing boss
REAR_BOSS_X1 = 49.0;
SHAFT_TIP_X = 11.0;
MOTOR_TOP = AXIS_Z + CAN_H / 2;        // 17.9

// gears m0.5
PINION_T = 8;  SPUR_T = 40;  MOD = 0.5;
GEAR_X0 = 11.5; GEAR_X1 = 15.5;        // spur gear face (outer face on the print bed)
GEAR_HUB_L = 0.8;                      // hub on the inner side (11.5 .. 16.3)
GEAR_BACKLASH = 0.10;                  // tooth thinning for printing (mm on the pitch circle)
CLR = 0.25;                            // printing clearance

// frame
BASE_T   = AXIS_Z - CAN_H / 2;         // 2.9 mm : motor rests on the base
WALL     = 1.8;
FRONT_X0 = CAN_X0 - BOSS_L;            // 18.8 : the boss pocket starts here
PLATE_X0 = 16.8;                       // motor plate is 3.7 mm thick (pinion ends at 15.5)
OUTER_X0 = 8.5; OUTER_X1 = 10.5;       // outer axle wall (hangs in the notch)
HANG_Z   = 0.0;                        // lowest point (flat bottom -> prints without supports)
AXLE_D   = 2.0;
AXLE_L   = 20.0;                       // brass rod, 2 mm
AXLE_END_X = 19.3;                     // blind end of the axle hole (axle pushed in until it stops)
WHEEL_X1 = 7.2;                        // inner face of the wheel (0.3 mm from the spacer boss)
TOWER_D  = 9.6;
TOWER_TOP = 15.0;                      // = deck bottom
TOWER_FRONT_CLIP = 65.6;               // front tower must not reach into the motor can

// deck (battery box carrier, printed upside down)
DECK_TOP  = 20.5;                      // battery box floor
DECK_UNDER = 18.0;                     // underside over the motors (motor top 17.9)
DECK_X0 = 24.5; DECK_X1 = 75.5;
DECK_FRONT = [57.0, 65.5];             // front bar (y)
DECK_REAR  = [87.0, 100.5];            // rear bar (y)
NUT_AF = 5.5; NUT_H = 2.4;
NUT_POCKET_AF = NUT_AF + 0.25;
TOWER_NUT_Z0 = 15.8;                   // nut for the M3x20 sits on this floor (screw tip ends at 18.4)

// battery box BH-331-3ASTH-150MM: 58 x 48.3 x 17, two 3.5 mm holes (90 deg countersink) 30 mm apart
BOX_L = 58.0; BOX_W = 48.3; BOX_H = 17.0;
BOX_C = [50, 76];
BOX_HOLES = [[50, 61], [50, 91]];

// skid at H5 (50,4): between the bodies of PS3 (x <= 45.35) and PS4 (x >= 54.65)
// Lite: H5 = (50,11), 7 mm behind the centre sensor (its body ends at y = 5.7, the skid starts at y = 6.7)
SKID_XY = LITE ? [50, 11] : [50, 4];
SENSOR_XS = LITE ? [38, 50, 62] : [20, 32, 44, 56, 68, 80];
SKID_H = 4.0;                          // = PCB bottom .. floor  (print 3.5 / 4.0 / 4.5 to tune sensor height)
SKID_D = 8.6;

// snap-in skid (default since 2026-10-05: no screw, no nylon nut)
CLIP_X0 = -1.2;                        // print face; the pin is flattened 0.3 mm here. body x = -1.2 .. 3.8
CLIP_PIN_D = 3.0; CLIP_BARB_D = 3.75;  // PCB hole is 3.2 mm (drilled)
CLIP_SLIT = 0.8; CLIP_POCKET_D = 4.2; CLIP_ROOT = 2.2;

// claw deck (option): holds the battery box with 4 claws instead of 2 screws
BOX_SHOULDER_H = 15.0;                 // height of the box's long wall at the claws (datasheet 15.0 +-0.5) - MEASURE YOUR BOX
BOX_UCUT = [20.8, 36.6]; BOX_UCUT_H = 7.0;   // finger cut in the long walls (from the left end of the box)
CLAW_X = [31, 65];                     // on the box "shoulders" (not on the U-cut, not over J1)
CLAW_T = 1.4; CLAW_W = 6; CLAW_GAP = 0.15; CLAW_LIP = 0.7; CLAW_ROOT_Z = 16.5;
PEG_D = 3.2; PEG_H = 1.2;              // pegs drop into the box's floor holes (3.5 mm) and locate it

// ---------------------------------------------------------------- helpers
module can_profile(r = CAN_R, h = CAN_H) {     // FA-130 cross-section in the y-z plane
    intersection() { circle(r = r); square([2 * r + 2, h], center = true); }
}

module along_x(x0, len) {                      // extrude a y-z profile along +x, centred on the motor axis
    translate([x0, MOTOR_Y, AXIS_Z]) rotate([0, 90, 0]) rotate([0, 0, 90]) linear_extrude(len) children();
}

module motor_left() {
    color("silver") along_x(CAN_X0, CAN_X1 - CAN_X0) can_profile();
    color("white") translate([CAN_X1, MOTOR_Y, AXIS_Z]) rotate([0, 90, 0])
        cylinder(d = 10, h = REAR_BOSS_X1 - CAN_X1);
    // terminals on the rounded sides of the end cap
    color("gold") for (s = [-1, 1]) translate([CAN_X1, MOTOR_Y + s * 9.2 - 0.6, AXIS_Z - 1.5]) cube([3.5, 1.2, 3]);
    color("silver") translate([FRONT_X0, MOTOR_Y, AXIS_Z]) rotate([0, 90, 0]) cylinder(d = BOSS_D, h = BOSS_L);
    color("gray") translate([SHAFT_TIP_X, MOTOR_Y, AXIS_Z]) rotate([0, 90, 0]) cylinder(d = 2, h = FRONT_X0 - SHAFT_TIP_X);
}

module gear_disc(teeth, x0, x1, y, col) {
    color(col) translate([x0, y, AXIS_Z]) rotate([0, 90, 0])
        cylinder(d = MOD * (teeth + 2), h = x1 - x0);
}

module m3_hole(h = 40) { translate([0, 0, -h / 2]) cylinder(d = 3.3, h = h); }
module nut_pocket(depth) { cylinder(d = NUT_POCKET_AF / cos(30), h = depth, $fn = 6); }

// ---------------------------------------------------------------- involute spur gear (2D)
function inv_deg(a) = (tan(a) - a * PI / 180) * 180 / PI;     // involute function, degrees in / out
function pol(R, a) = [R * cos(a), R * sin(a)];

module gear2d(m, z, pa = 20, b = 0.1, steps = 8) {
    r  = m * z / 2;
    rb = r * cos(pa);
    ra = r + m;
    rf = r - 1.25 * m;
    hp = ((PI * m / 2 - b) / (2 * r)) * 180 / PI;              // half tooth angle on the pitch circle
    function hal(R) = hp + inv_deg(pa) - inv_deg(acos(rb / max(R, rb)));
    pts = [ for (i = [0 : z - 1])
              let (c = i * 360 / z)
              each concat(
                  [ for (k = [0 : steps]) let (R = rb + (ra - rb) * k / steps) pol(R, c - hal(R)) ],
                  [ for (k = [steps : -1 : 0]) let (R = rb + (ra - rb) * k / steps) pol(R, c + hal(R)) ],
                  [ pol(rf, c + hal(rb)), pol(rf, c + 360 / z - hal(rb)) ]) ];
    polygon(pts);
}

// ---------------------------------------------------------------- frame (left)
module tower(h) {
    translate([h[0], h[1], 0]) intersection() {
        cylinder(d = TOWER_D, h = TOWER_TOP);
        translate([-TOWER_D, -TOWER_D, -1])
            cube([2 * TOWER_D, (h[1] < MOTOR_Y ? TOWER_FRONT_CLIP - h[1] : 100.5 - h[1]) + TOWER_D, TOWER_TOP + 2]);
    }
}
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

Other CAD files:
hardware/mechanical/frame_left.stl
hardware/mechanical/skid_screw_h40.stl

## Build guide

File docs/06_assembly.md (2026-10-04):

# 06. 組み立て手順書（先生用・子ども用）

> 対象: 小学校高学年〜中学生（はんだ付けは先生がそばについて行う）
> 所要時間: 約 4〜5 時間（Pico とモジュールのヘッダを先生が事前に付けておけば約 3 時間）
> 最終更新: 2026-10-05（rev.A1: 枠・デッキ・電池ボックスはねじ、スキッドはツメで固定。テープ・接着剤は使わない）

---

## 0. 準備

| 道具 | 備考 |
|---|---|
| はんだごて（温度調節付き 330〜350℃）、こて台、こて先クリーナー | |
| はんだ（φ0.8mm、やに入り） | 子ども向けには溶けやすい共晶はんだ（鉛入り）が扱いやすい。使用後は必ず手を洗う。鉛フリーを使う場合は温度を 360℃ 前後に |
| ニッパー、ラジオペンチ | 足を切るときは **保護めがね**（足が飛ぶ） |
| **プラスドライバー No.1**（M3 ねじ用） | ねじは全部 M3（長さ 20 mm と 8 mm の 2 種類） |
| テスター | 組み立て後のショート確認 |
| マスキングテープ | はんだ付けのとき部品を仮止めして裏返すため（**完成品にはテープを使わない**） |
| はがき 1 枚 | 車輪と枠のすき間を作る（4.3） |

### 先生が事前に準備しておくもの

| もの | 作り方・買い方 |
|---|---|
| 3D プリント部品（1 台分） | P1S で印刷（`hardware/mechanical/README.md`）: 枠 L・R、デッキ、平歯車 40T ×2、車輪 ×2、スキッド（`skid_clip_h40.stl`） |
| 車軸 ×2 | 真鍮丸棒 φ2 mm を **20 mm** に金のこで切り、切り口のバリをやすりで取る |
| ピニオンギヤ ×2 | タミヤ 15289（8T）。モーター軸への圧入は先生がやってもよい（4.2） |
| ねじ 1 台分 | なべ小ねじ M3×20 ×4、皿小ねじ M3×8 ×2、六角ナット M3 ×6（`05_bom.md`）。ツメ版デッキを使うなら皿ねじ 0・ナット 4 |
| O リング P-24 ×2 | タイヤ |

### 基板の「表」と「裏」

- **表（部品面）**: 白い文字で `100` `10k` `1k` などの値、`START` `まえ` などが書いてある面。ほとんどの部品はこちらから差す。
- **裏（センサー面）**: `Linetracer2` の大きな文字と `センサーはこちらの面に付ける` がある面。**センサー 6 個だけはこちらから差す。**
- 前（進行方向）は `FRONT / まえ` と書いてある側。

---

## 1. はんだ付けの順番（背の低い部品から）

各ステップで「差す → 裏返して はんだ → 足を切る」をくり返す。

| 順番 | 部品 | 場所（シルク） | 向き・注意 |
|---|---|---|---|
| ① | 抵抗 **100Ω（茶黒茶）** ×7 | `100` と書いてある所（センサー列の左側 6 本、ブザー横 1 本） | 向きはない。足を 10mm 間隔に曲げる |
| ② | 抵抗 **10kΩ（茶黒橙）** ×8 | `10k`（センサー列の右側 6 本、右端 2 本） | |
| ③ | 抵抗 **1kΩ（茶黒赤）** ×4 | `1k`（左上 1 本、LED の下 3 本） | |
| ④ | ダイオード D1（1N5819） | `1N5819` | **帯（灰色の線）の向きをシルクの帯に合わせる** |
| ⑤ | **センサー PS1〜PS6（LBR-123F）** | **裏面**の小さな四角 | **裏から差す**。レンズ（窓）が外（床）を向く。**角が欠けている所（ピン1）をシルクの●・欠けに合わせる**。基板にぴったり押し付けて、表側ではんだ付け。足の間隔が 1.8mm と狭いので、はんだが隣とつながらないように少しずつ |
| ⑥ | トランジスタ Q1（2SC1815） | 左上 `Q1` | **平らな面をシルクの平らな線に合わせる** |
| ⑦ | セラミックコンデンサ 0.1µF ×4 | C3〜C6 | 向きはない |
| ⑧ | IC U2（TC4051BP）またはICソケット | 中央の `U2` | **半円の切り欠きを左に**（シルクの切り欠きに合わせる） |
| ⑨ | LED ×3（**黄緑**=PWR、赤=LED1、黄=LED2） | 右上 `D4:PWR` `D2:LED1` `D3:LED2` | **長い足が＋**。四角いランド側が−（短い足） |
| ⑩ | タクトスイッチ ×2 | 右上角 `SW1 START` `SW2 SELECT` | パチッと奥まで差し込む |
| ⑪ | 電解コンデンサ 470µF ×2 | `C1` `C2` | **長い足が＋**（四角いランド）。白い帯の側が− |
| ⑫ | 電池コネクタ J1（XH 2P） | 右下 `BAT 3xAA / でんち` | **先に電池ボックスのプラグを差し込み、赤い線が「＋」(RED) 側に来る向きで基板に置いてから** はんだ付け（逆だと壊れる） |
| ⑬ | モータードライバ U3（モジュール） | 中央右の長方形 `TC78H653` | モジュールにピンヘッダを先にはんだ付け（先生）。**切り欠き（VM・LARGE 側）を前（上）にする**。シルクの `1` がモジュールの LARGE ピン |
| ⑭ | Raspberry Pi Pico | 大きな長方形 | Pico にピンヘッダ（20ピン×2）を付けてから（先生）、**USB を基板の左端に向けて**差し、40 本はんだ付け |
| ⑮ | （オプション）ブザー BZ1 | 左の丸。穴が 3 つある | 秋月の 13 mm ブザー（PKM13EPYH4000-A0）は **`+` の四角い穴と、真ん中の `13` の穴**。足の長いほう（＋の印）を `+` に。12 mm の物（足の間隔 7.6 mm）なら `+` と右の `12` の穴 |

> ⚠ **J2（I2C）と J3（EXT）は付けなくてよい**（発展課題用）。

---

## 2. 電気のチェック（電池を入れる前に！）

テスターの抵抗レンジで:

| 測る所 | 正常 | おかしいとき |
|---|---|---|
| J1 の＋ と − | 数百Ω 以上（コンデンサの充電でだんだん上がる） | 0Ω 近く → どこかショート（ブリッジ）。C1 の向き、U3 のはんだを確認 |
| C2 の＋ と − （VSYS） | 数 kΩ 以上 | Pico の VSYS/GND のブリッジ |
| センサーの足どうし | つながっていない | はんだブリッジ |

目視: Pico の 40 ピン、センサーの 4 ピン、U2 の 16 ピンにブリッジ（隣とつながったはんだ）がないか。

---

## 3. はじめての電源（USB だけ）

1. 電池ボックスのスイッチは **OFF**。
2. Pico を USB でパソコンにつなぐ → **黄緑の PWR LED が点く**。点かなければ、Pico のヘッダのはんだ、D4 の向きを確認。
3. MicroPython を書き込み、サンプル `01_led_blink.py` → `02_buttons_buzzer.py` → `03_sensor_monitor.py` を順に動かす（`07_firmware.md`）。
4. `03_sensor_monitor.py` で、白い紙の上と黒い線の上で値が変わるか確認（白: 大きい / 黒: 小さい）。変わらないセンサーは向き・はんだを確認。

---

## 4. 機械の組み立て（ねじだけで固定する）

exploded

全体の重なり（下から）: **基板 → 枠（モーター・ギヤ・車輪入り）→ デッキ（青）→ 電池ボックス**。
M3×20 のねじ 4 本が、基板の裏から「基板・枠・デッキ」をまとめて締める（ナットはデッキの中）。スキッドはツメで差し込むだけ。

| ねじ・ツメ | 数 | どこ |
|---|----|---|
| なべ小ねじ M3×20 | 4 | 基板の裏 → 枠の柱 → デッキのナット |
| 皿小ねじ M3×8 | 2 | 電池ボックスの中 → デッキのナット（ツメ版デッキなら不要） |
| 六角ナット M3 | 6 | デッキの六角の穴（上に 4、下に 2）（ツメ版デッキなら上の 4 だけ） |
| ツメ | — | スキッド（標準）、電池ボックス（ツメ版デッキのとき） |

### 4.1 スキッド（前のすべり足）

1. 基板の裏（センサー面）の前中央 `SKID` の穴に、スキッドのピン（2 本に割れたほう）を差し込み、**パチッと言うまで押し込む**。丸いそりの面が床側、そりの向きは前後（細長いほうが進む向き）。
2. 表に出たピンの先が開いていれば OK。外すときは表のピンの先をつまんですぼめ、裏へ押し出す。
   - センサーの高さを変えたいときは `skid_clip_h35.stl`（3.5 mm、床に近づく）/ `skid_clip_h45.stl`（4.5 mm）に替える。
   - ツメが折れたら印刷し直す（約 4 分）。予備のねじ版 `skid_screw_h40.stl` は M3×8 皿ねじ＋**ナイロンナット**で留める（金属ナットはセンサーのはんだに触れるので不可）。

### 4.2 モーターの準備

1. モーターの端子 2 か所に電線（長さ約 6cm）をはんだ付け。**赤い印のある端子 → 赤い線**。
2. （おすすめ）端子の間に 0.1µF を 1 個はんだ付けすると雑音が減る。
3. **ピニオンギヤ 8T** をモーター軸に押し込む。**ピニオンの外側の面が軸の先端とそろう**所まで（入れすぎない）。万力やペンチで、**モーター本体を押さないように**軸の反対側（後ろの出っぱり）を支えて押す。

### 4.3 ギヤボックス（左右 2 つ作る）

1. **平歯車 40T** を、枠の「外側の壁」と「内側の軸受け」の間に入れる。**出っぱり（ハブ）がモーター側**。
2. **車軸**を枠の外側から穴に入れ、平歯車の穴に押し込みながら、**止まるところまで**差す（平歯車はきつくはまる。壁が平歯車を支えるので位置は自動で決まる）。
3. 車軸の外側の端に**車輪**を押し込む。車輪と枠の丸い出っぱりの間に**はがきを 1 枚はさんで**押し込み、はがきを抜く（すき間 約 0.3 mm）。
4. 車輪のみぞに **O リング**をはめる。
5. **モーター**を枠のゆりかごに入れる: 前の丸い出っぱり（φ6）を壁の丸い穴に先に入れてから、後ろを押し下げてパチッとはめる。ピニオンと平歯車がかみ合う。
6. 車輪を指で回して、引っかかりなく回るか確認。

### 4.4 電池ボックスをデッキにつける

1. デッキ（青い板）の**上の面**の六角の穴 4 つに、ナットを 1 個ずつ入れる。
2. デッキの**下の面**のまん中の六角の穴 2 つにナットを入れ、指で押さえておく。
3. 電池ボックス（**スイッチが左・線が右**）をデッキに載せ、ボックスの中の 2 つの皿穴から **M3×8 皿ねじ**でデッキの下のナットに締める。
   → これで上の 4 つのナットは電池ボックスの下に閉じこめられ、落ちない。

**ツメ版デッキ（`deck_clip.stl`）を使う場合**: 手順 2・3 のかわりに、電池を抜いたボックスを（スイッチが左・線が右）デッキの上から押し込む。底の 2 つの穴にデッキの突起が入り、前後 4 本のツメがパチッと壁の上にかかる。外すときは前後のツメを外に開いて持ち上げる（`hardware/mechanical/README.md` §2.1）。

### 4.5 基板に取り付ける

1. 左右のギヤボックスを、基板の表のシルク（`MOTOR L` / `MOTOR R` の四角）に合わせて置く。
2. **基板の裏から M3×20 なべねじ**を 4 本、基板の穴 → 枠の柱の穴に通す（車輪とスキッドで立たせておけば、ねじは下に落ちない）。
3. モーターの線を `M1 LEFT`（左）/ `M2 RIGHT`（右）の穴へ。**まず後ろの小さい穴（引っぱり防止）に上から通し、裏から前の大きい穴に戻して表ではんだ付け**。赤い線を `+` に。
   - **デッキを付ける前に**はんだ付けすること（付けた後はこてが届かない）。
4. **電池を抜いた**電池ボックス＋デッキを、柱の上に載せる（4 本のねじの先がデッキの穴に入る）。
5. 全体を手で押さえたまま**ひっくり返し**（電池ボックスが下）、上を向いた基板の裏から 4 本のねじをドライバーで締める。ナットはデッキの中で回らないので、ねじを回すだけでよい。
6. 元に戻して電池を入れ、電池ボックスのプラグを J1 に差す。余った電池の線は電池ボックスの横に沿わせる。

> 分解するときは逆の順（ねじ 4 本を外すと、電池ボックス＋デッキがまとめて外れる）。

---

## 5. 走らせる前の確認

1. **車輪を浮かせて**（箱の上などに乗せて）`04_motor_test.py` を実行 → 「前進」で両輪が前に回るか確認。逆なら `linetracer.py` の `LEFT_INVERT` / `RIGHT_INVERT` を変える（またはモーターの線を入れ替える）。
2. `main.py` を書き込み、コースの線の上に置いて START → 自動キャリブレーション（その場で左右に回る）→ もう一度 START で走る。
3. うまく走らないときは `07_firmware.md` の「調整のしかた」。

---

## 6. よくあるトラブル

| 症状 | 原因と対策 |
|---|---|
| USB でつないでも PWR LED が点かない | Pico のはんだ不良。3V3（36番ピン）と GND の間の電圧を確認 |
| 電池を入れると PWR が点くがモーターが回らない | 電池ボックスのスイッチ、J1 の向き（赤＝＋）、U3 のはんだ。`04_motor_test.py` の電池電圧表示が 3V 以下なら電池切れ |
| モーターが一瞬回ってすぐ止まる | ドライバの過電流保護（ISD）。ライブラリが 0.1 秒ごとに自動復帰するが、何度も止まるならギヤの噛みすぎ・車輪の擦れ（重い）を確認 |
| ギヤがガリガリ鳴る／重い | 平歯車の印刷が太い。`linetracer2_mech.scad` の `GEAR_BACKLASH` を 0.15 にして印刷し直す（`hardware/mechanical/README.md`） |
| 車輪が空回りする | 車輪または平歯車の穴がゆるい。印刷し直す（穴を 0.05 mm 小さく）。テープ・接着剤では直さない |
| 走り出すと Pico がリセットする | 電池が弱い。ニッケル水素電池を使う、速度レベルを下げる |
| センサーの値が白黒で変わらない | センサーの向き（裏から差したか、ピン1の向き）、はんだ。床とセンサーの距離（2〜3mm）も確認。スキッドの高さを替える（4.1） |
| ある場所だけ線を外れる | 窓からの光、コースのつなぎ目。外乱光キャンセル（`ambient_cancel = True`）を使う |

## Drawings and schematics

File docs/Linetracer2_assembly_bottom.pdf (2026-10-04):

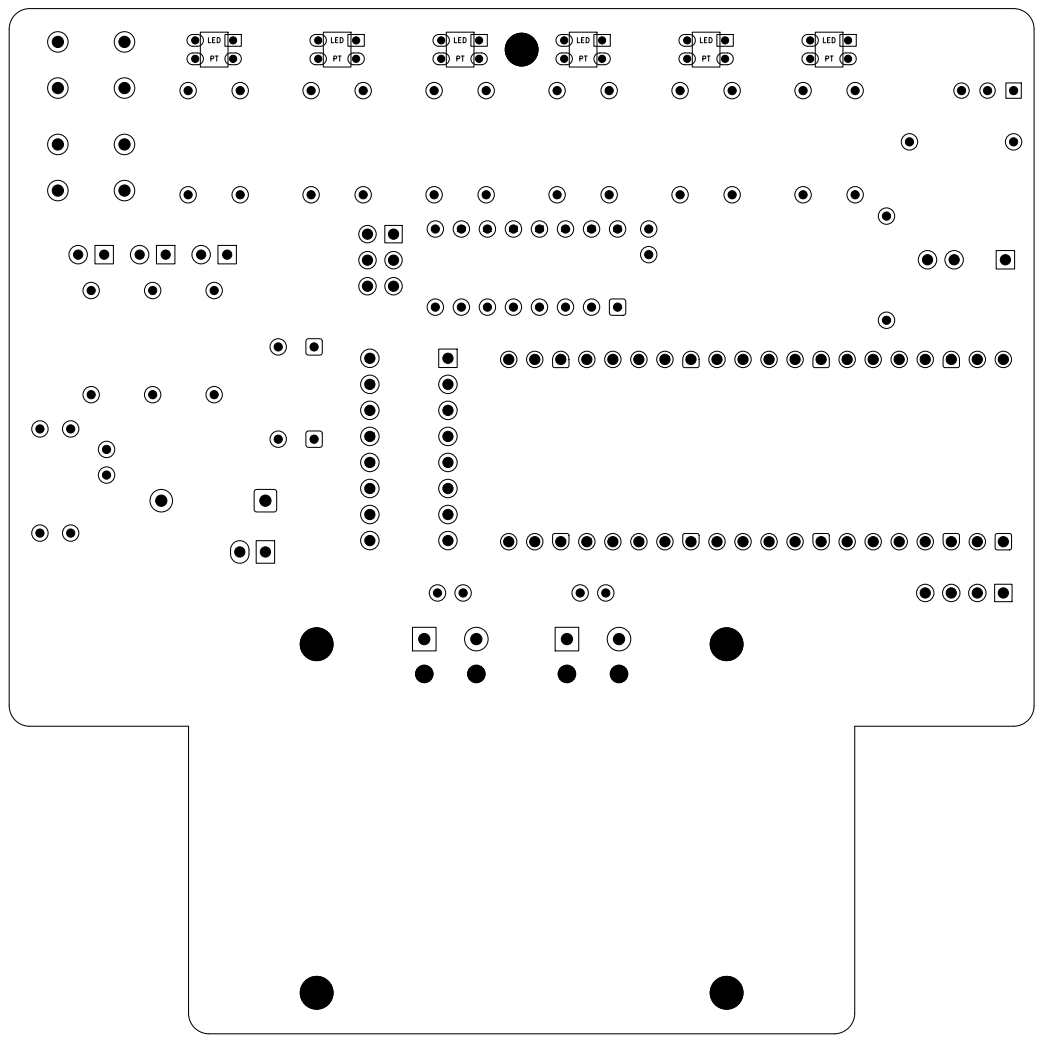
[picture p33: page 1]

Size: A4 | Rev:
KiCad E.D.A. 10.0.6 | Id: 1/1

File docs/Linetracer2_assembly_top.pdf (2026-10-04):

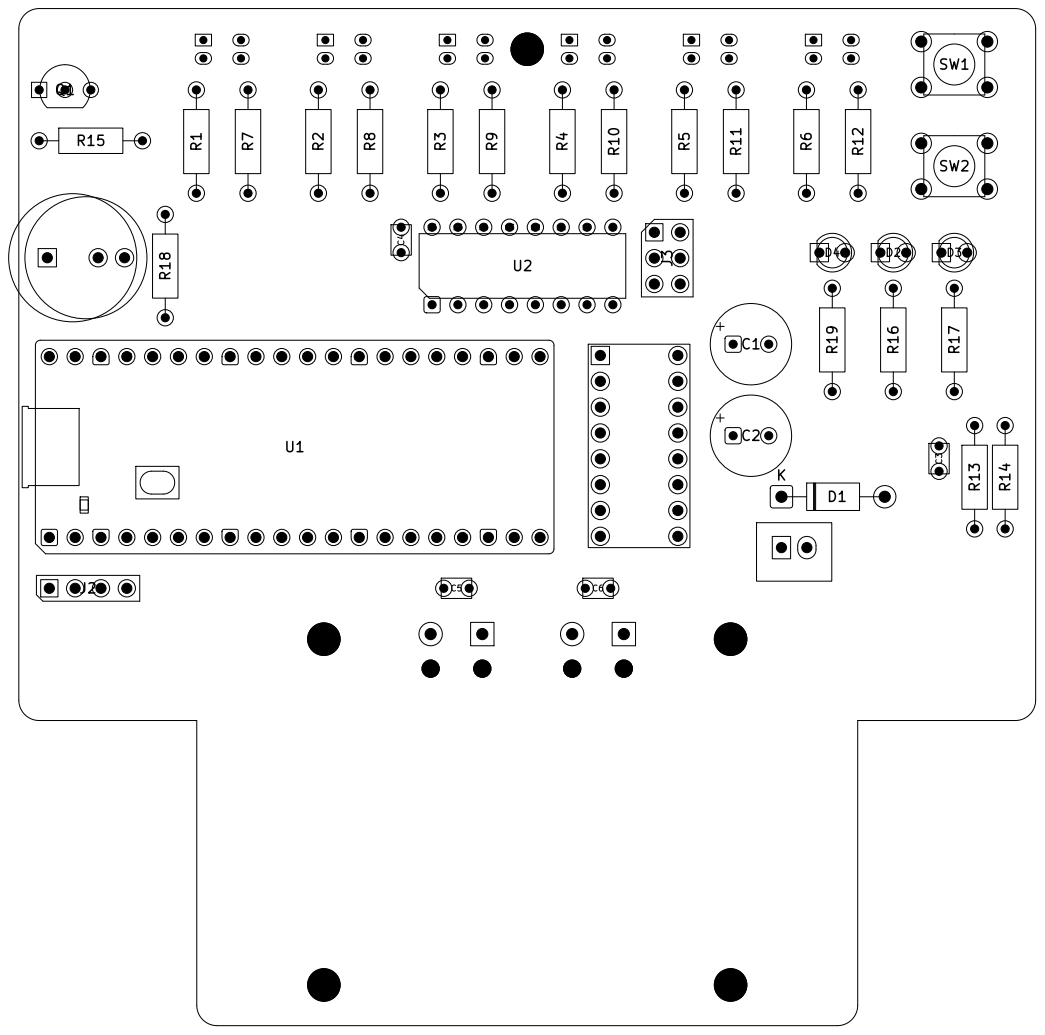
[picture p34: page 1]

Size: A4 | Rev:
KiCad E.D.A. 10.0.6 | Id: 1/1

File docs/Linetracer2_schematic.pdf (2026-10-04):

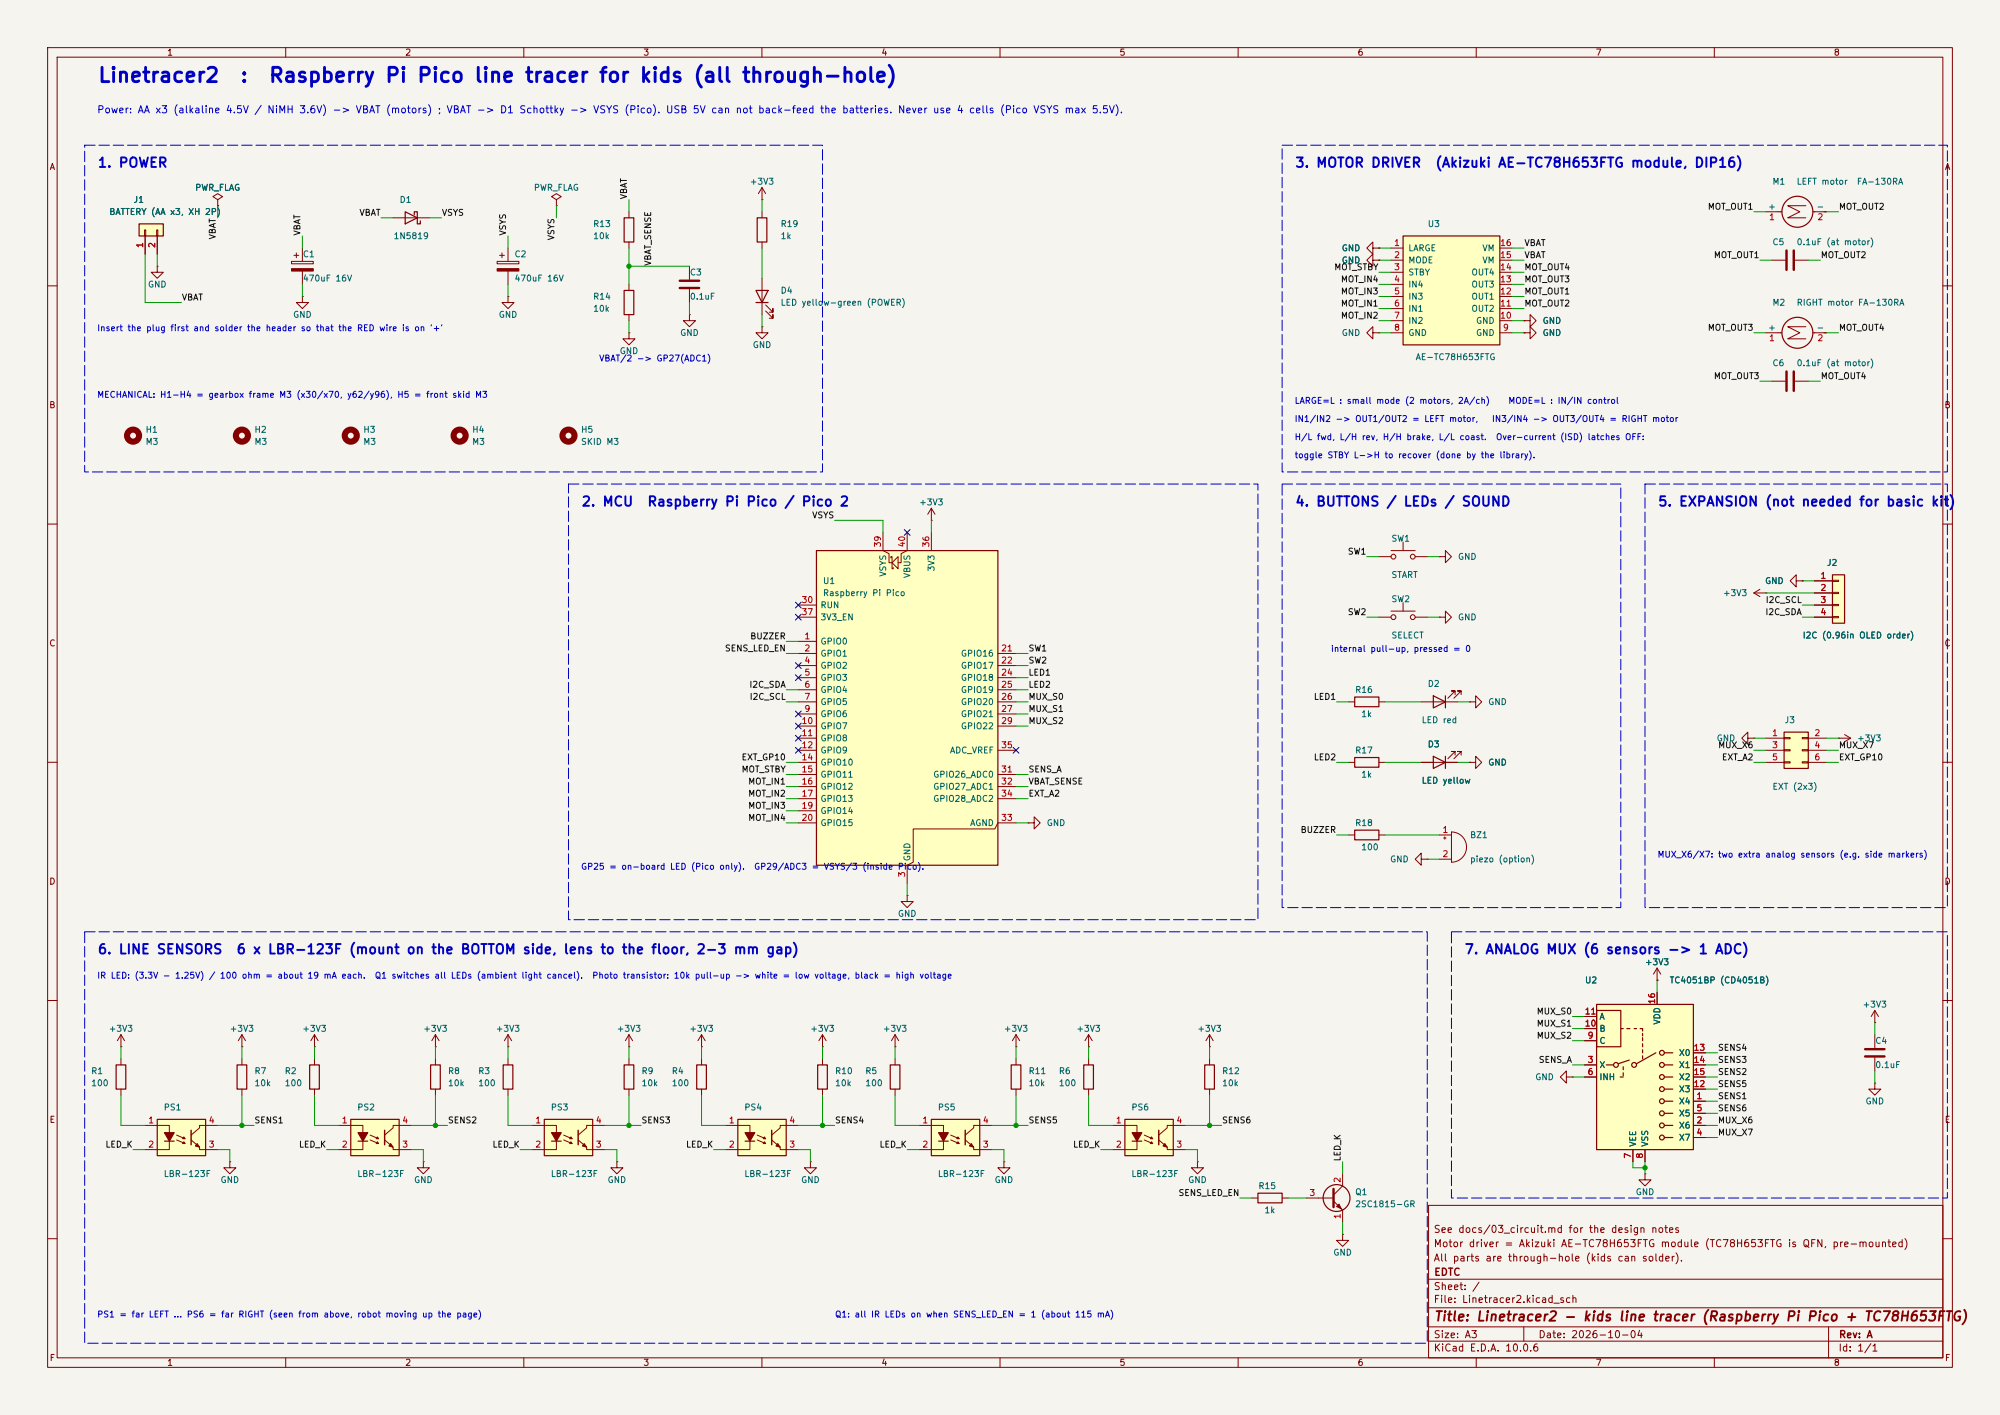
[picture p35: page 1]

Linetracer2 : Raspberry Pi Pico line tracer for kids (all through-hole)

Power: AA x3 (alkaline 4.5V / NiMH 3.6V) -> VBAT (motors) ; VBAT -> D1 Schottky -> VSYS (Pico). USB 5V can not back-feed the batteries. Never use 4 cells (Pico VSYS max 5.5V).

MECHANICAL: H1-H4 = gearbox frame M3 (x30/x70, y62/y96), H5 = front skid M3 1. POWER

3. MOTOR DRIVER (Akizuki AE-TC78H653FTG module, DIP16)

J1 BATTERY (AA x3, XH 2P) GND

H/L fwd, L/H rev, H/H brake, L/L coast. Over-current (ISD) latches OFF: toggle STBY L->H to recover (done by the library).

2. MCU Raspberry Pi Pico / Pico 2

5. EXPANSION (not needed for basic kit)

internal pull-up, pressed = 0

SENS2 MUX_X7 MUX_X6 MUX_X6/X7: two extra analog sensors (e.g. side markers)

6. LINE SENSORS 6 x LBR-123F (mount on the BOTTOM side, lens to the floor, 2-3 mm gap)
0.1uF +3V3 +3V3 GND +3V3
IR LED: (3.3V - 1.25V) / 100 ohm = about 19 mA each. Q1 switches all LEDs (ambient light cancel). Photo transistor: 10k pull-up -> white = low voltage, black = high voltage

7. ANALOG MUX (6 sensors -> 1 ADC)

See docs/03_circuit.md for the design notes
Motor driver = Akizuki AE-TC78H653FTG module (TC78H653FTG is QFN, pre-mounted)
All parts are through-hole (kids can solder).
EDTC
Sheet: /
File: Linetracer2.kicad_sch
Title: Linetracer2 - kids line tracer (Raspberry Pi Pico + TC78H653FTG)

PS1 = far LEFT ... PS6 = far RIGHT (seen from above, robot moving up the page)

Q1: all IR LEDs on when SENS_LED_EN = 1 (about 115 mA)

Size: A3 | Rev: A | F Date: 2026-10-04
KiCad E.D.A. 10.0.6 | Id: 1/1

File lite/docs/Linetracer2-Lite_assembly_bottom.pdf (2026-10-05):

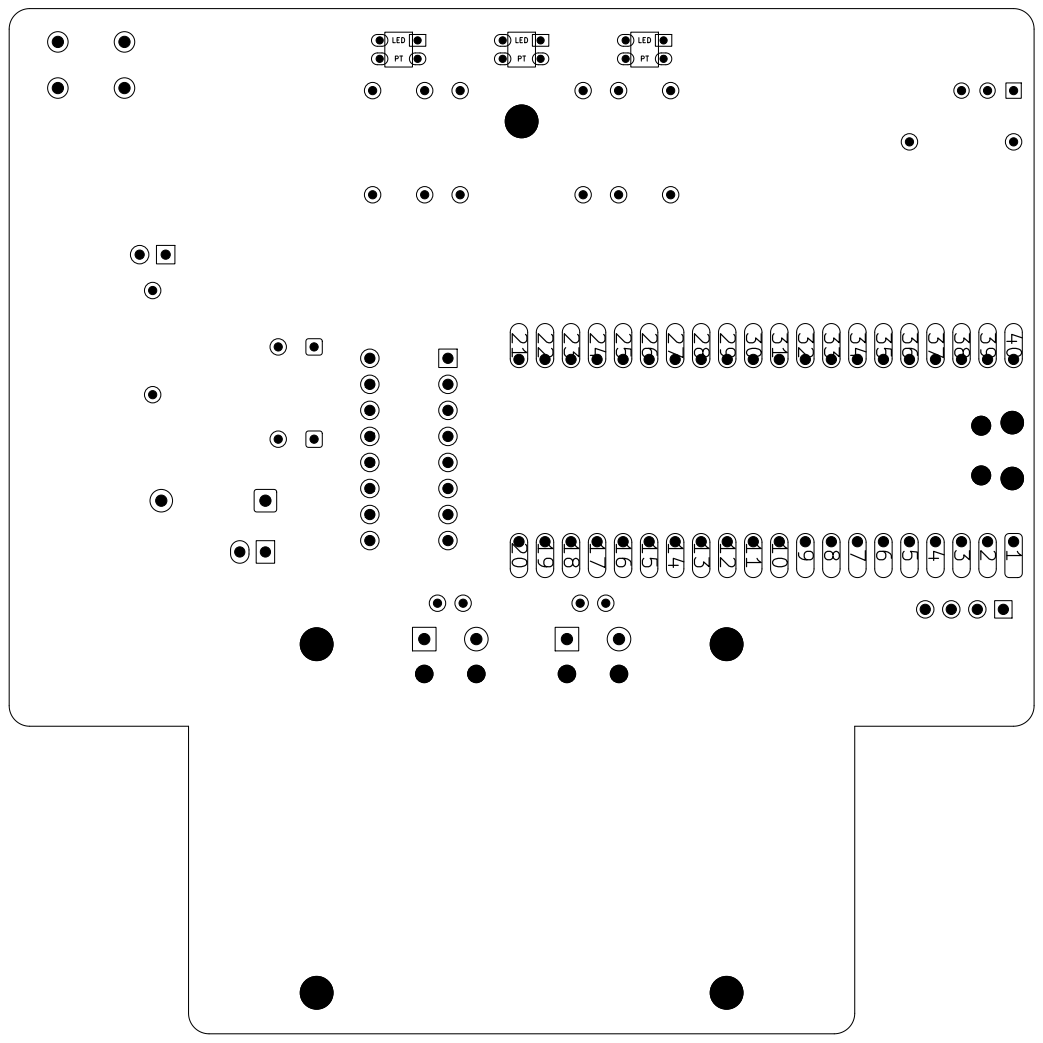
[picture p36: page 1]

Size: A4 | Rev:
KiCad E.D.A. 10.0.6 | Id: 1/1

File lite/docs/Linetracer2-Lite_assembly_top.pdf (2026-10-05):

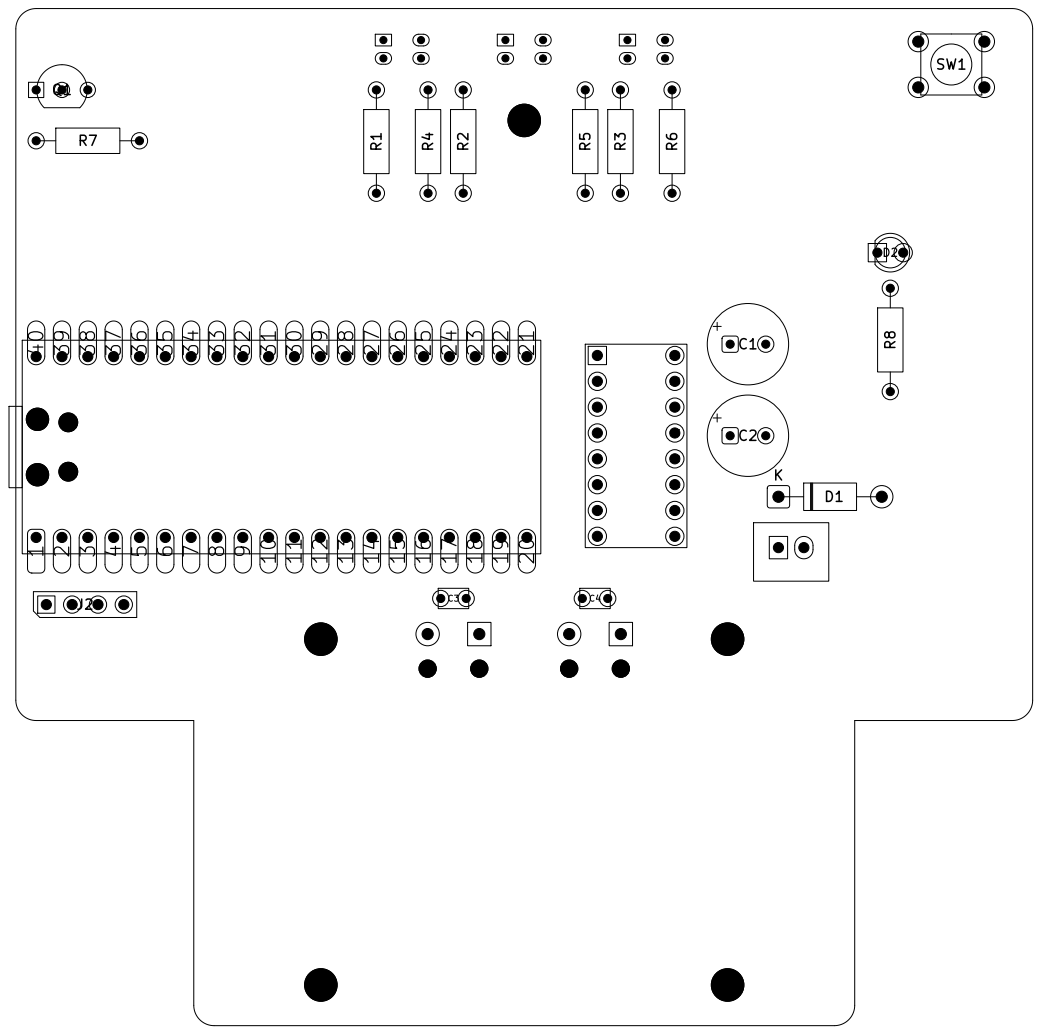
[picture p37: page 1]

Size: A4 | Rev:
KiCad E.D.A. 10.0.6 | Id: 1/1

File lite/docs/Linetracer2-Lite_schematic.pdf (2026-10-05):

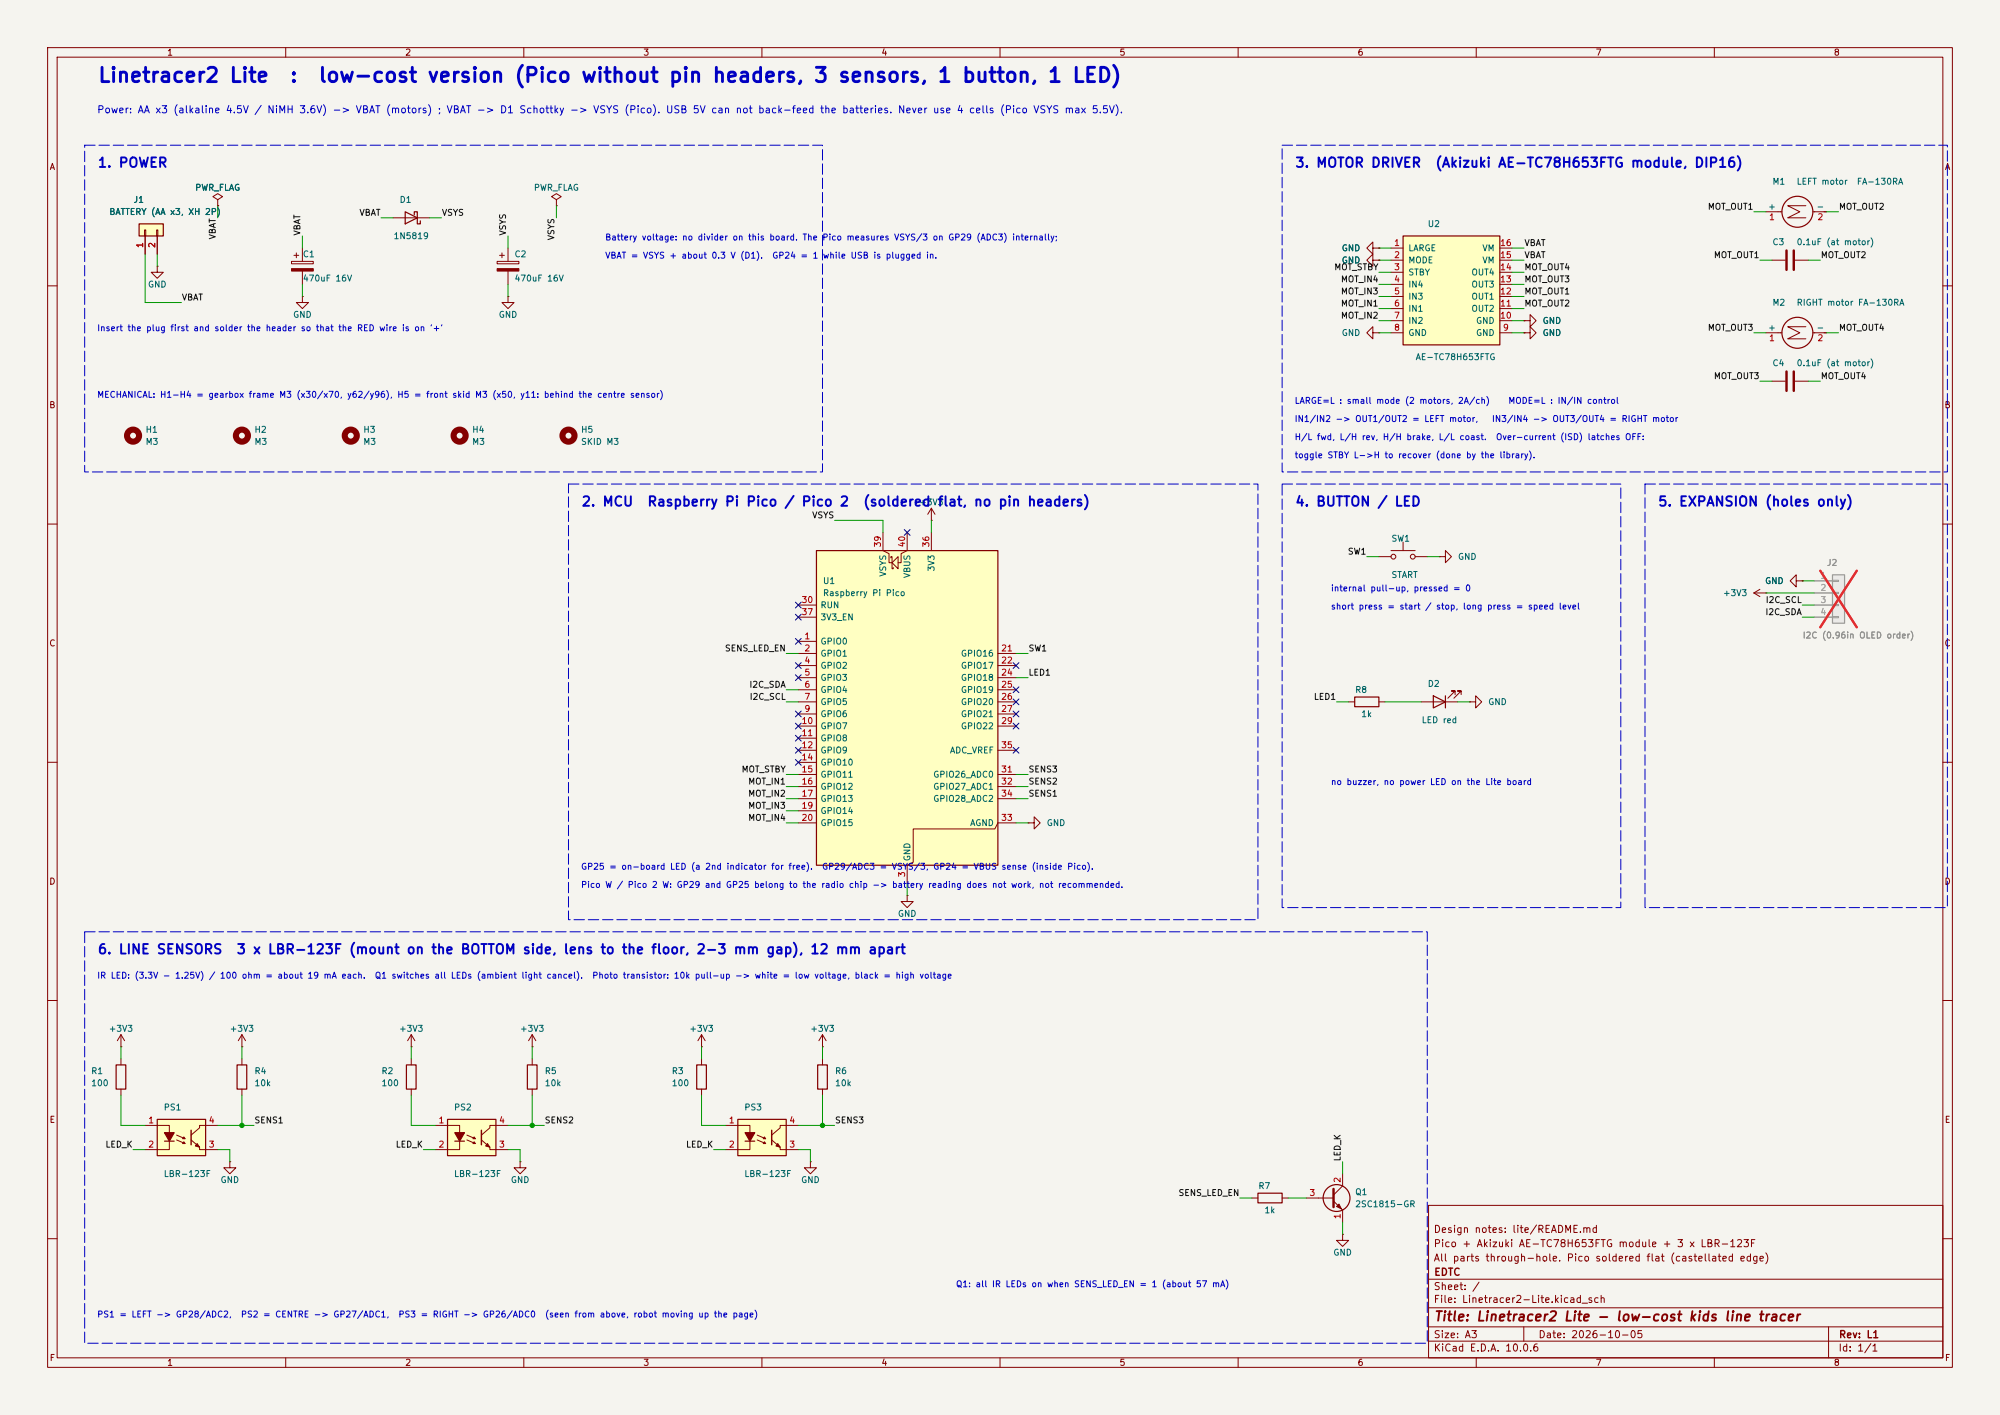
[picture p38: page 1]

Linetracer2 Lite : low-cost version (Pico without pin headers, 3 sensors, 1 button, 1 LED)

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

3. MOTOR DRIVER (Akizuki AE-TC78H653FTG module, DIP16)

Insert the plug first and solder the header so that the RED wire is on '+' MECHANICAL: H1-H4 = gearbox frame M3 (x30/x70, y62/y96), H5 = front skid M3 (x50, y11: behind the centre sensor)

toggle STBY L->H to recover (done by the library).

internal pull-up, pressed = 0 4. BUTTON / LED

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

Design notes: lite/README.md
Pico + Akizuki AE-TC78H653FTG module + 3 x LBR-123F
All parts through-hole. Pico soldered flat (castellated edge)
EDTC
Sheet: /
File: Linetracer2-Lite.kicad_sch
Title: Linetracer2 Lite - low-cost kids line tracer

Q1: all IR LEDs on when SENS_LED_EN = 1 (about 57 mA)

Size: A3 | Rev: L1 | F Date: 2026-10-05
KiCad E.D.A. 10.0.6 | Id: 1/1

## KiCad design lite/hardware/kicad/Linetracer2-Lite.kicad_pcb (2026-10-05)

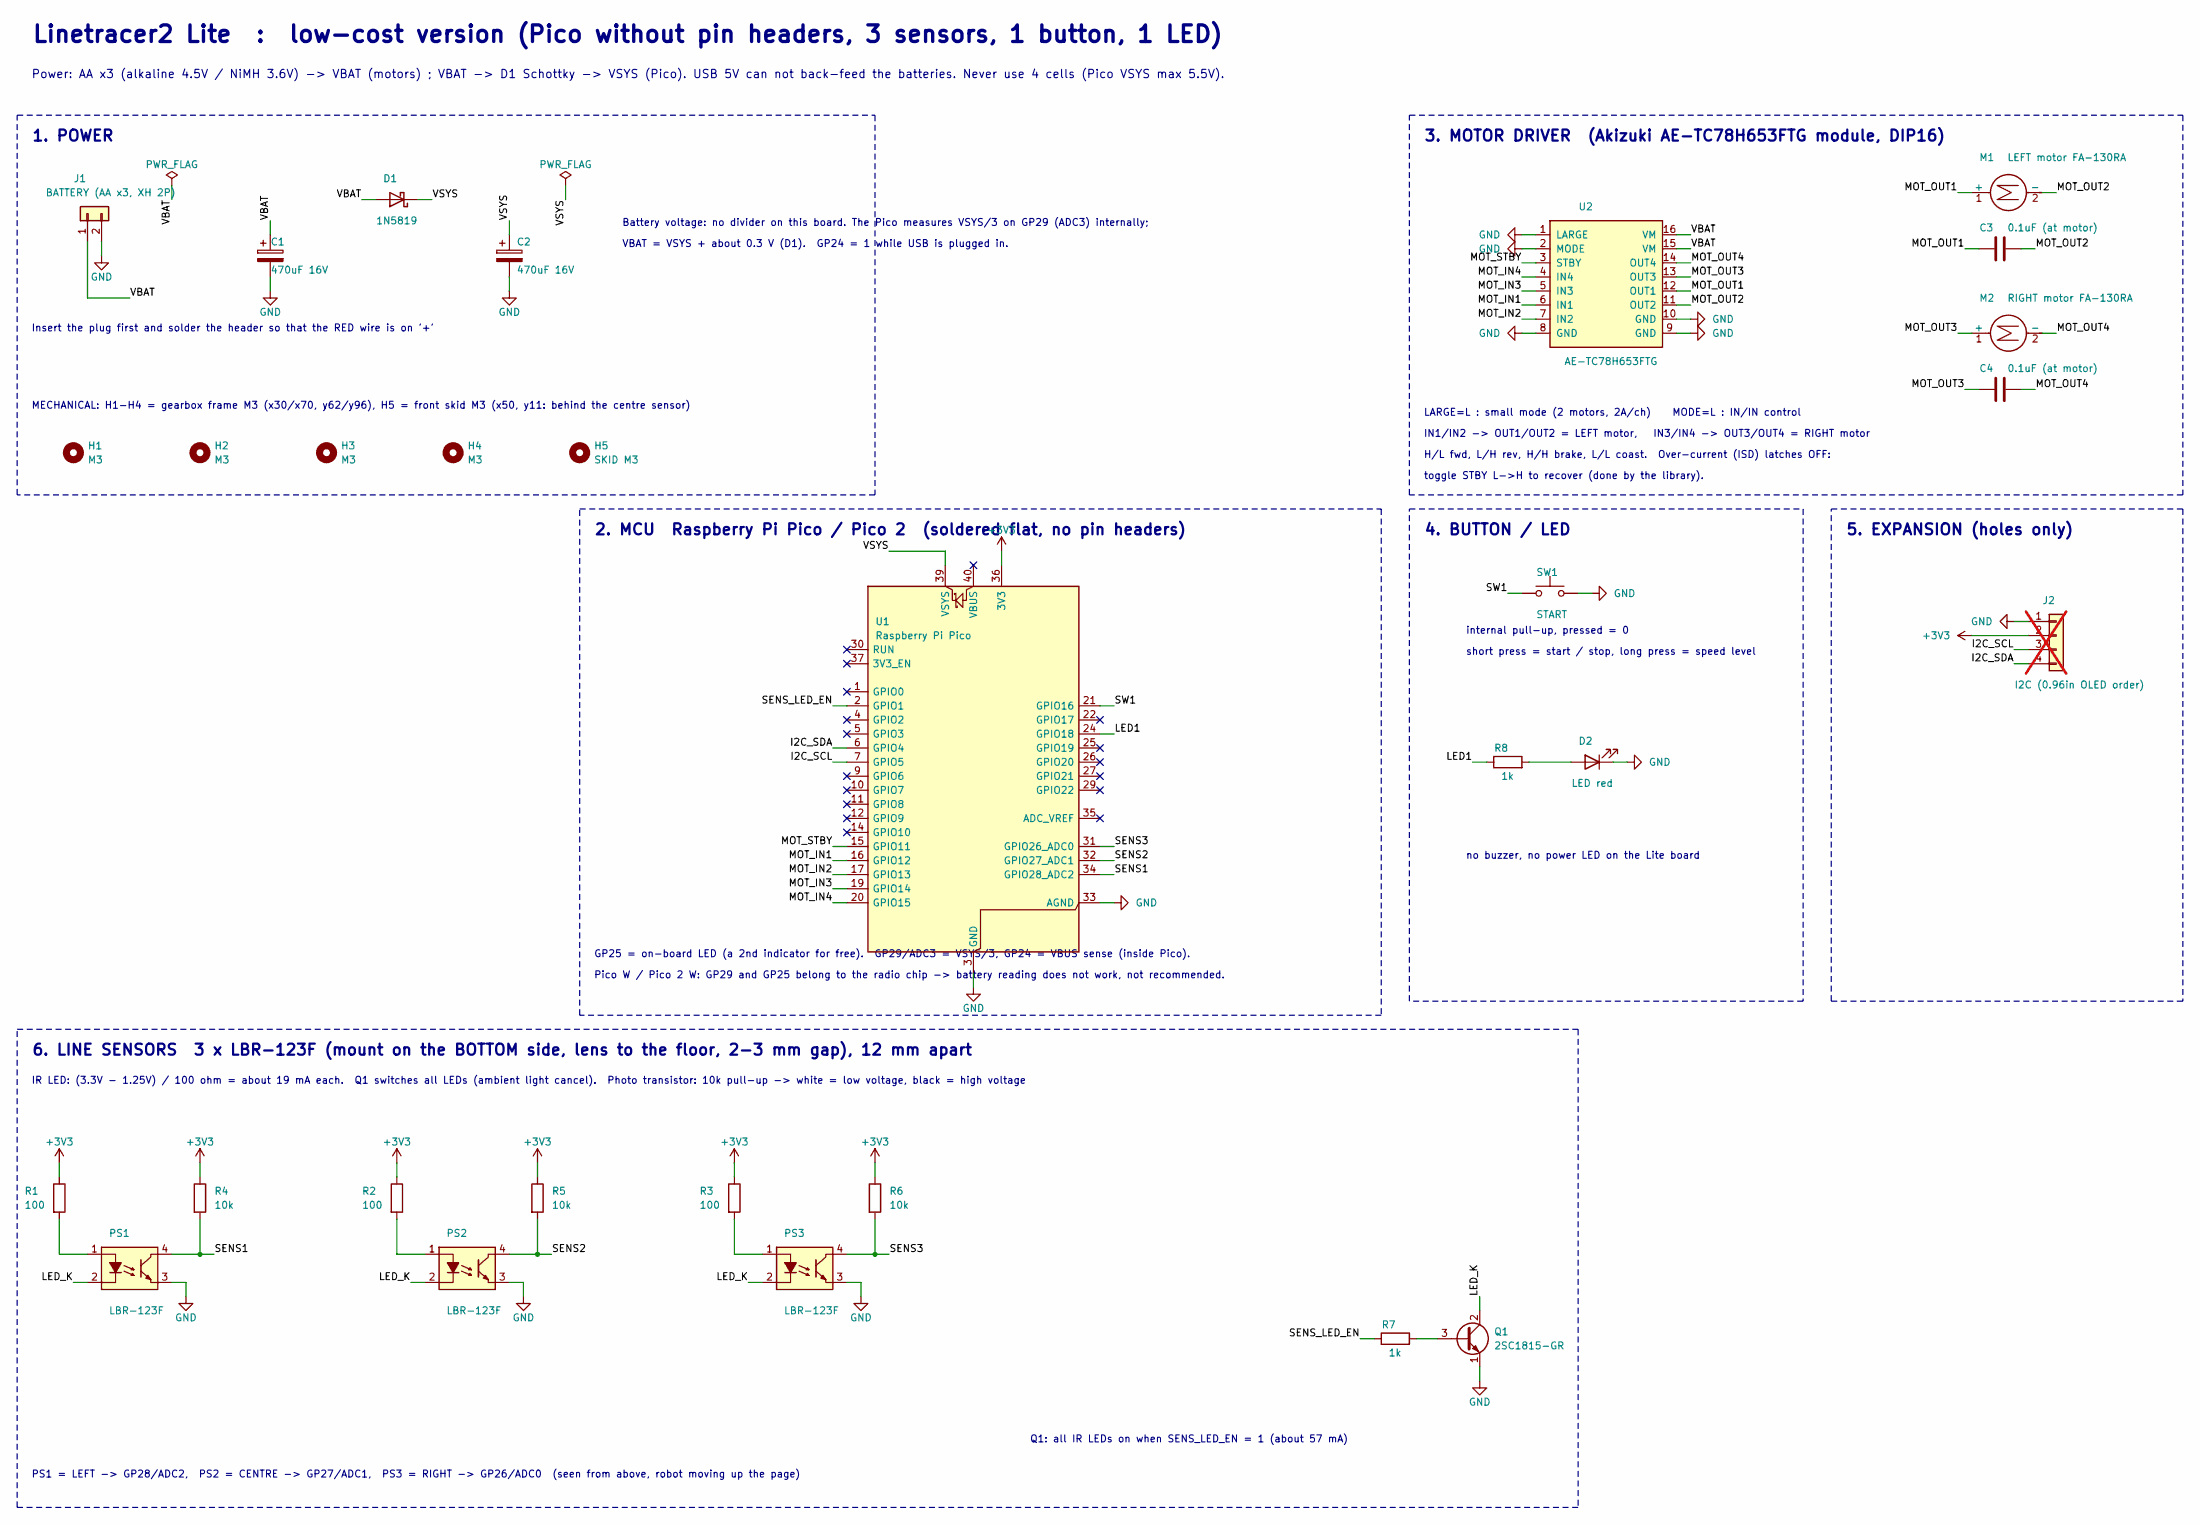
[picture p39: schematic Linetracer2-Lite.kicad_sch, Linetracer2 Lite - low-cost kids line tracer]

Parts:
C1, C2: 470uF 16V; CP_Radial_D8.0mm_P3.50mm
C3, C4: 0.1uF (at motor); C_Disc_D3.0mm_W2.0mm_P2.50mm
D1: 1N5819; D_DO-41_SOD81_P10.16mm_Horizontal
D2: LED red; LED_D3.0mm
H1, H2, H3, H4: M3; MountingHole_3.2mm_M3
H5: SKID M3; MountingHole_3.2mm_M3
J1: BATTERY (AA x3, XH 2P); BatteryXH_2P
J2: I2C (0.96in OLED order); PinHeader_1x04_P2.54mm_Vertical; not fitted
M1: LEFT motor FA-130RA; MotorPads_2P_Relief
M2: RIGHT motor FA-130RA; MotorPads_2P_Relief
PS1, PS2, PS3: LBR-123F
Q1: 2SC1815-GR; TO-92_Inline_Wide
R1, R2, R3: 100; R_Axial_DIN0207_L6.3mm_D2.5mm_P10.16mm_Horizontal
R4, R5, R6: 10k; R_Axial_DIN0207_L6.3mm_D2.5mm_P10.16mm_Horizontal
R7, R8: 1k; R_Axial_DIN0207_L6.3mm_D2.5mm_P10.16mm_Horizontal
SW1: START; SW_PUSH_6mm
U1: Raspberry Pi Pico; RaspberryPi_Pico_DirectSolder
U2: AE-TC78H653FTG

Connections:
+3V3: J2.2, R1.1, R2.1, R3.1, R4.1, R5.1, R6.1, U1.36 (3V3)
/I2C_SCL: J2.3, U1.7 (GPIO5)
/I2C_SDA: J2.4, U1.6 (GPIO4)
/LED1: R8.1, U1.24 (GPIO18)
/LED_K: PS1.2 (K), PS2.2 (K), PS3.2 (K), Q1.2 (C)
/MOT_IN1: U1.16 (GPIO12), U2.6 (IN1)
/MOT_IN2: U1.17 (GPIO13), U2.7 (IN2)
/MOT_IN3: U1.19 (GPIO14), U2.5 (IN3)
/MOT_IN4: U1.20 (GPIO15), U2.4 (IN4)
/MOT_OUT1: C3.1, M1.1 (+), U2.12 (OUT1)
/MOT_OUT2: C3.2, M1.2 (-), U2.11 (OUT2)
/MOT_OUT3: C4.1, M2.1 (+), U2.13 (OUT3)
/MOT_OUT4: C4.2, M2.2 (-), U2.14 (OUT4)
/MOT_STBY: U1.15 (GPIO11), U2.3 (STBY)
/SENS1: PS1.4 (C), R4.2, U1.34 (GPIO28_ADC2)
/SENS2: PS2.4 (C), R5.2, U1.32 (GPIO27_ADC1)
/SENS3: PS3.4 (C), R6.2, U1.31 (GPIO26_ADC0)
/SENS_LED_EN: R7.1, U1.2 (GPIO1)
/SW1: SW1.1, U1.21 (GPIO16)
/VBAT: C1.1, D1.2 (A), J1.1, U2.15 (VM), U2.16 (VM)
/VSYS: C2.1, D1.1 (K), U1.39 (VSYS)
GND: C1.2, C2.2, D2.1 (K), J1.2, J2.1, PS1.3 (E), PS2.3 (E), PS3.3 (E), Q1.1 (E), SW1.2, U1.3 (GND), U1.8 (GND), U1.13 (GND), U1.18 (GND), U1.23 (GND), U1.28 (GND), U1.33 (AGND), U1.38 (GND), U2.1 (LARGE), U2.2 (MODE), U2.8 (GND), U2.9 (GND), U2.10 (GND)
unnamed: D2.2 (A), R8.2
unnamed: PS1.1 (A), R1.2
unnamed: PS2.1 (A), R2.2
unnamed: PS3.1 (A), R3.2
unnamed: Q1.3 (B), R7.2

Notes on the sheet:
IN1/IN2 -> OUT1/OUT2 = LEFT motor, IN3/IN4 -> OUT3/OUT4 = RIGHT motor
Power: AA x3 (alkaline 4.5V / NiMH 3.6V) -> VBAT (motors) ; VBAT -> D1 Schottky -> VSYS (Pico). USB 5V can not back-feed the batteries. Never use 4 cells (Pico VSYS max 5.5V).
LARGE=L : small mode (2 motors, 2A/ch) MODE=L : IN/IN control
2. MCU Raspberry Pi Pico / Pico 2 (soldered flat, no pin headers)
Insert the plug first and solder the header so that the RED wire is on '+'
6. LINE SENSORS 3 x LBR-123F (mount on the BOTTOM side, lens to the floor, 2-3 mm gap), 12 mm apart
no buzzer, no power LED on the Lite board
Pico W / Pico 2 W: GP29 and GP25 belong to the radio chip -> battery reading does not work, not recommended.
1. POWER
MECHANICAL: H1-H4 = gearbox frame M3 (x30/x70, y62/y96), H5 = front skid M3 (x50, y11: behind the centre sensor)
5. EXPANSION (holes only)
Q1: all IR LEDs on when SENS_LED_EN = 1 (about 57 mA)
PS1 = LEFT -> GP28/ADC2, PS2 = CENTRE -> GP27/ADC1, PS3 = RIGHT -> GP26/ADC0 (seen from above, robot moving up the page)
Battery voltage: no divider on this board. The Pico measures VSYS/3 on GP29 (ADC3) internally;
4. BUTTON / LED
VBAT = VSYS + about 0.3 V (D1). GP24 = 1 while USB is plugged in.
GP25 = on-board LED (a 2nd indicator for free). GP29/ADC3 = VSYS/3, GP24 = VBUS sense (inside Pico).
H/L fwd, L/H rev, H/H brake, L/L coast. Over-current (ISD) latches OFF:
3. MOTOR DRIVER (Akizuki AE-TC78H653FTG module, DIP16)
IR LED: (3.3V - 1.25V) / 100 ohm = about 19 mA each. Q1 switches all LEDs (ambient light cancel). Photo transistor: 10k pull-up -> white = low voltage, black = high voltage
short press = start / stop, long press = speed level
Linetracer2 Lite : low-cost version (Pico without pin headers, 3 sensors, 1 button, 1 LED)
internal pull-up, pressed = 0
toggle STBY L->H to recover (done by the library).

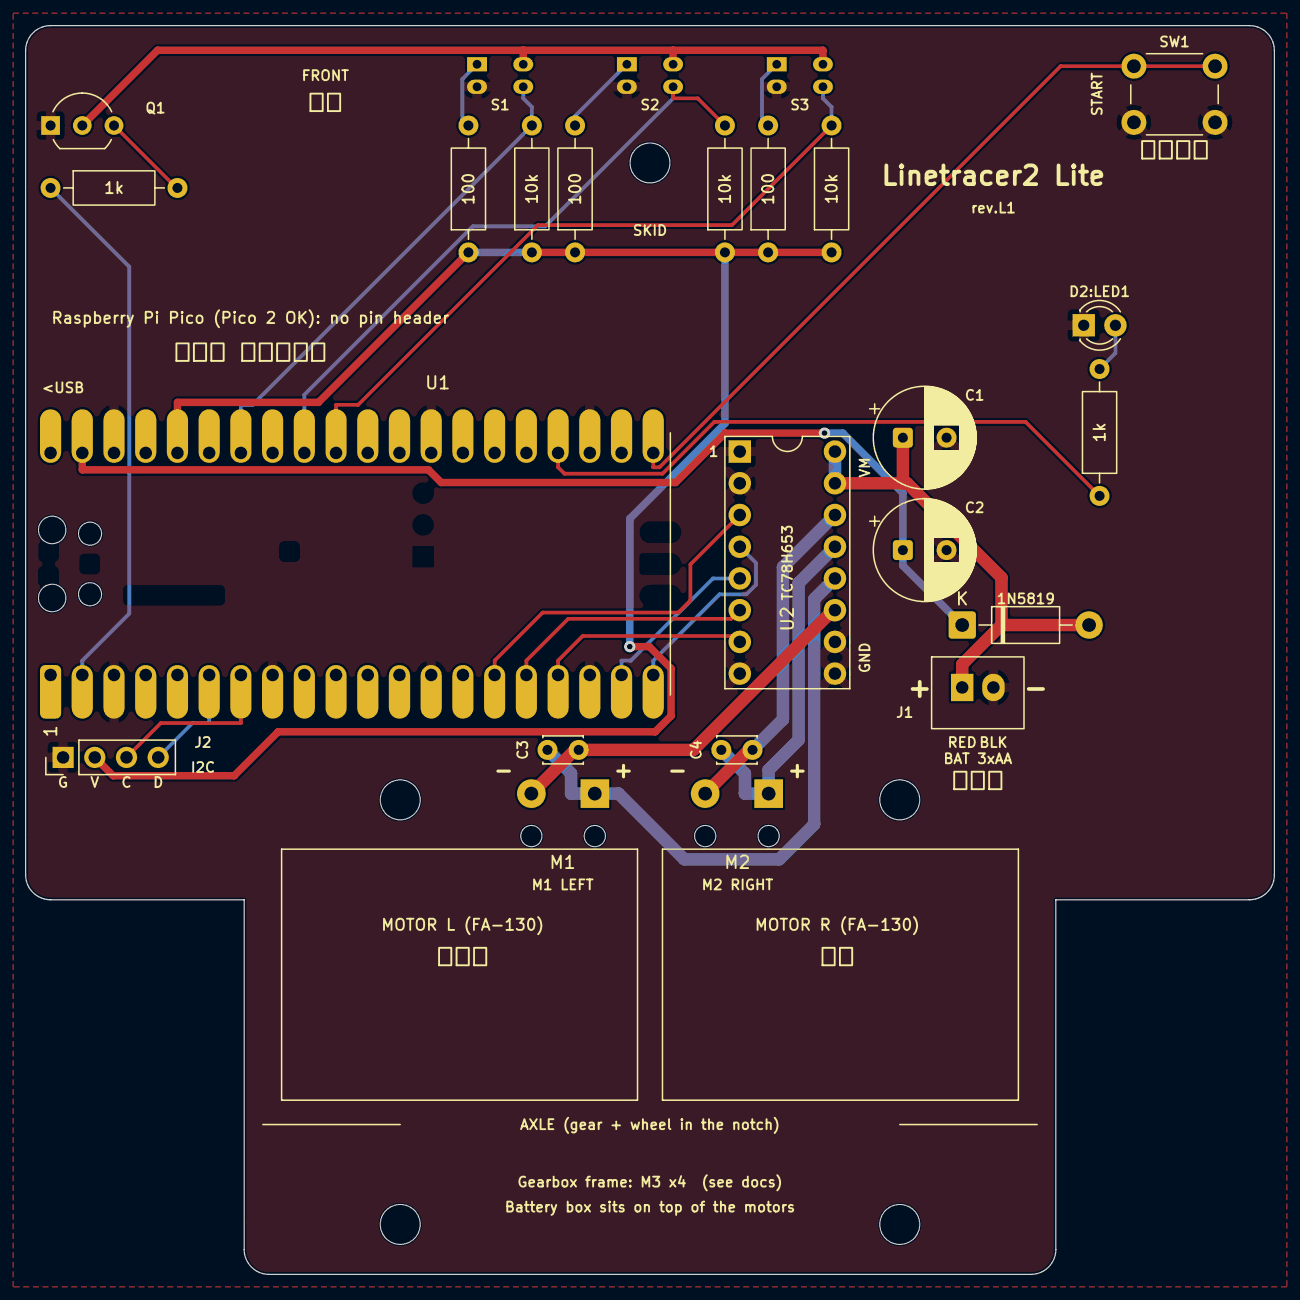
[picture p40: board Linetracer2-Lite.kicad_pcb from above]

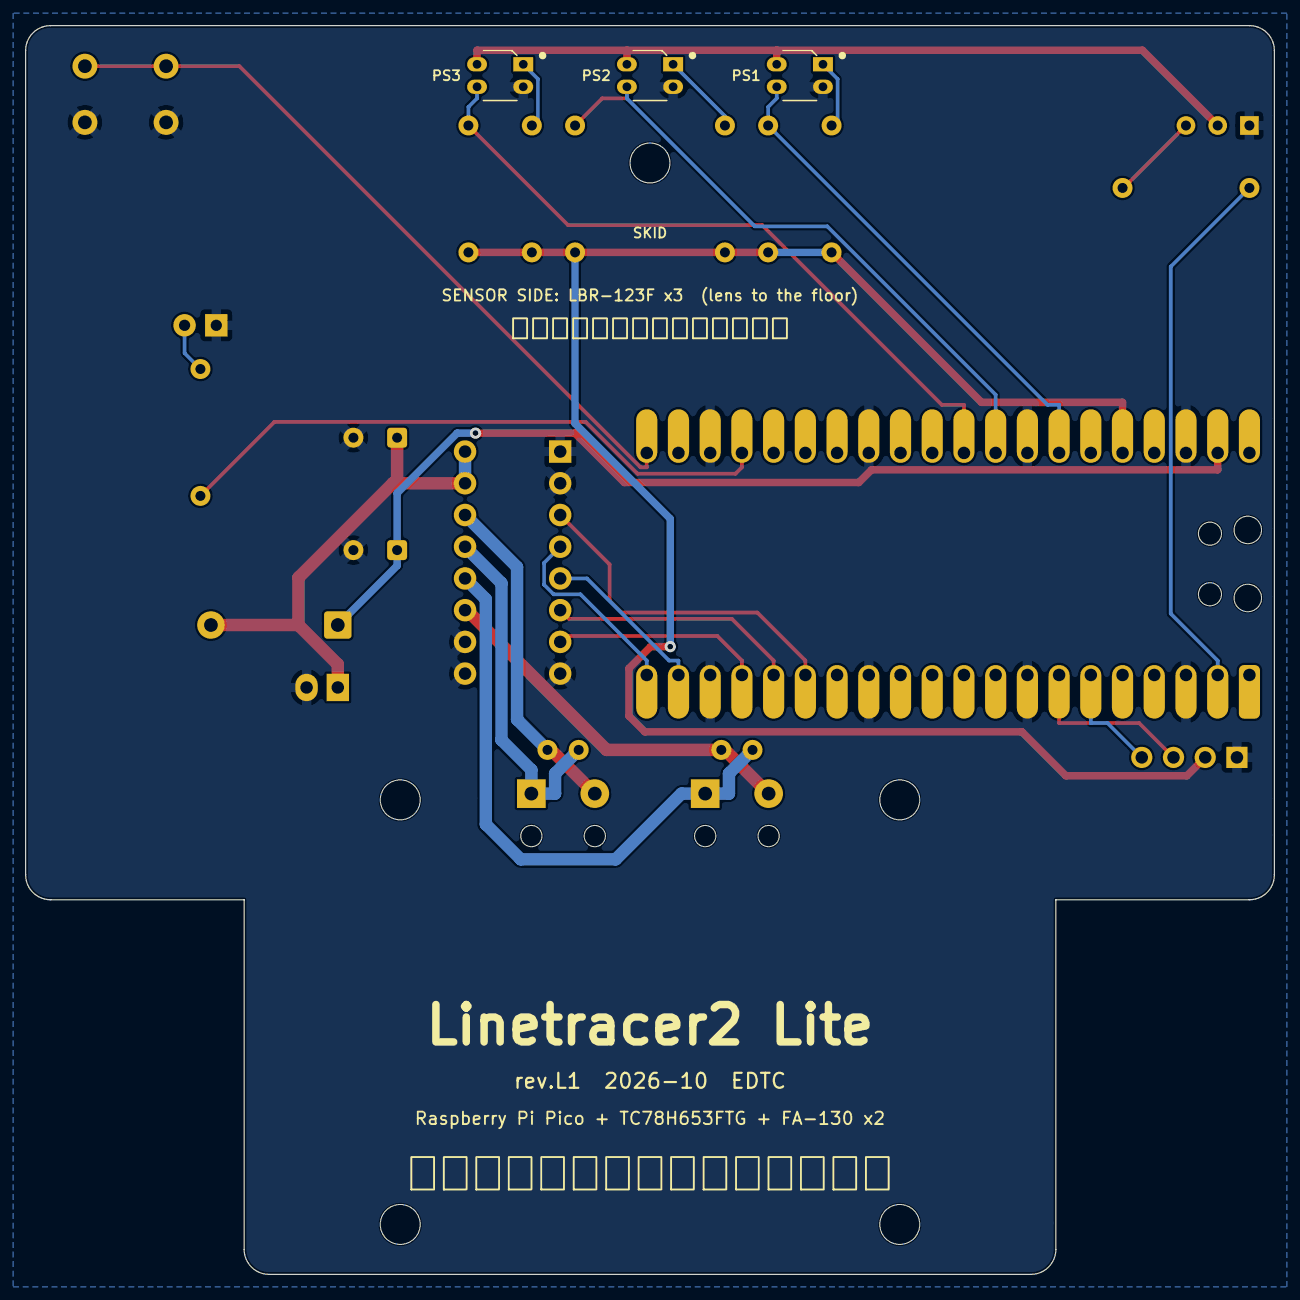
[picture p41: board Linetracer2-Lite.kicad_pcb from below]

Board: 2 copper layers, 100.0 x 100.0 mm, 30 parts (3 on the bottom side), 27 nets.

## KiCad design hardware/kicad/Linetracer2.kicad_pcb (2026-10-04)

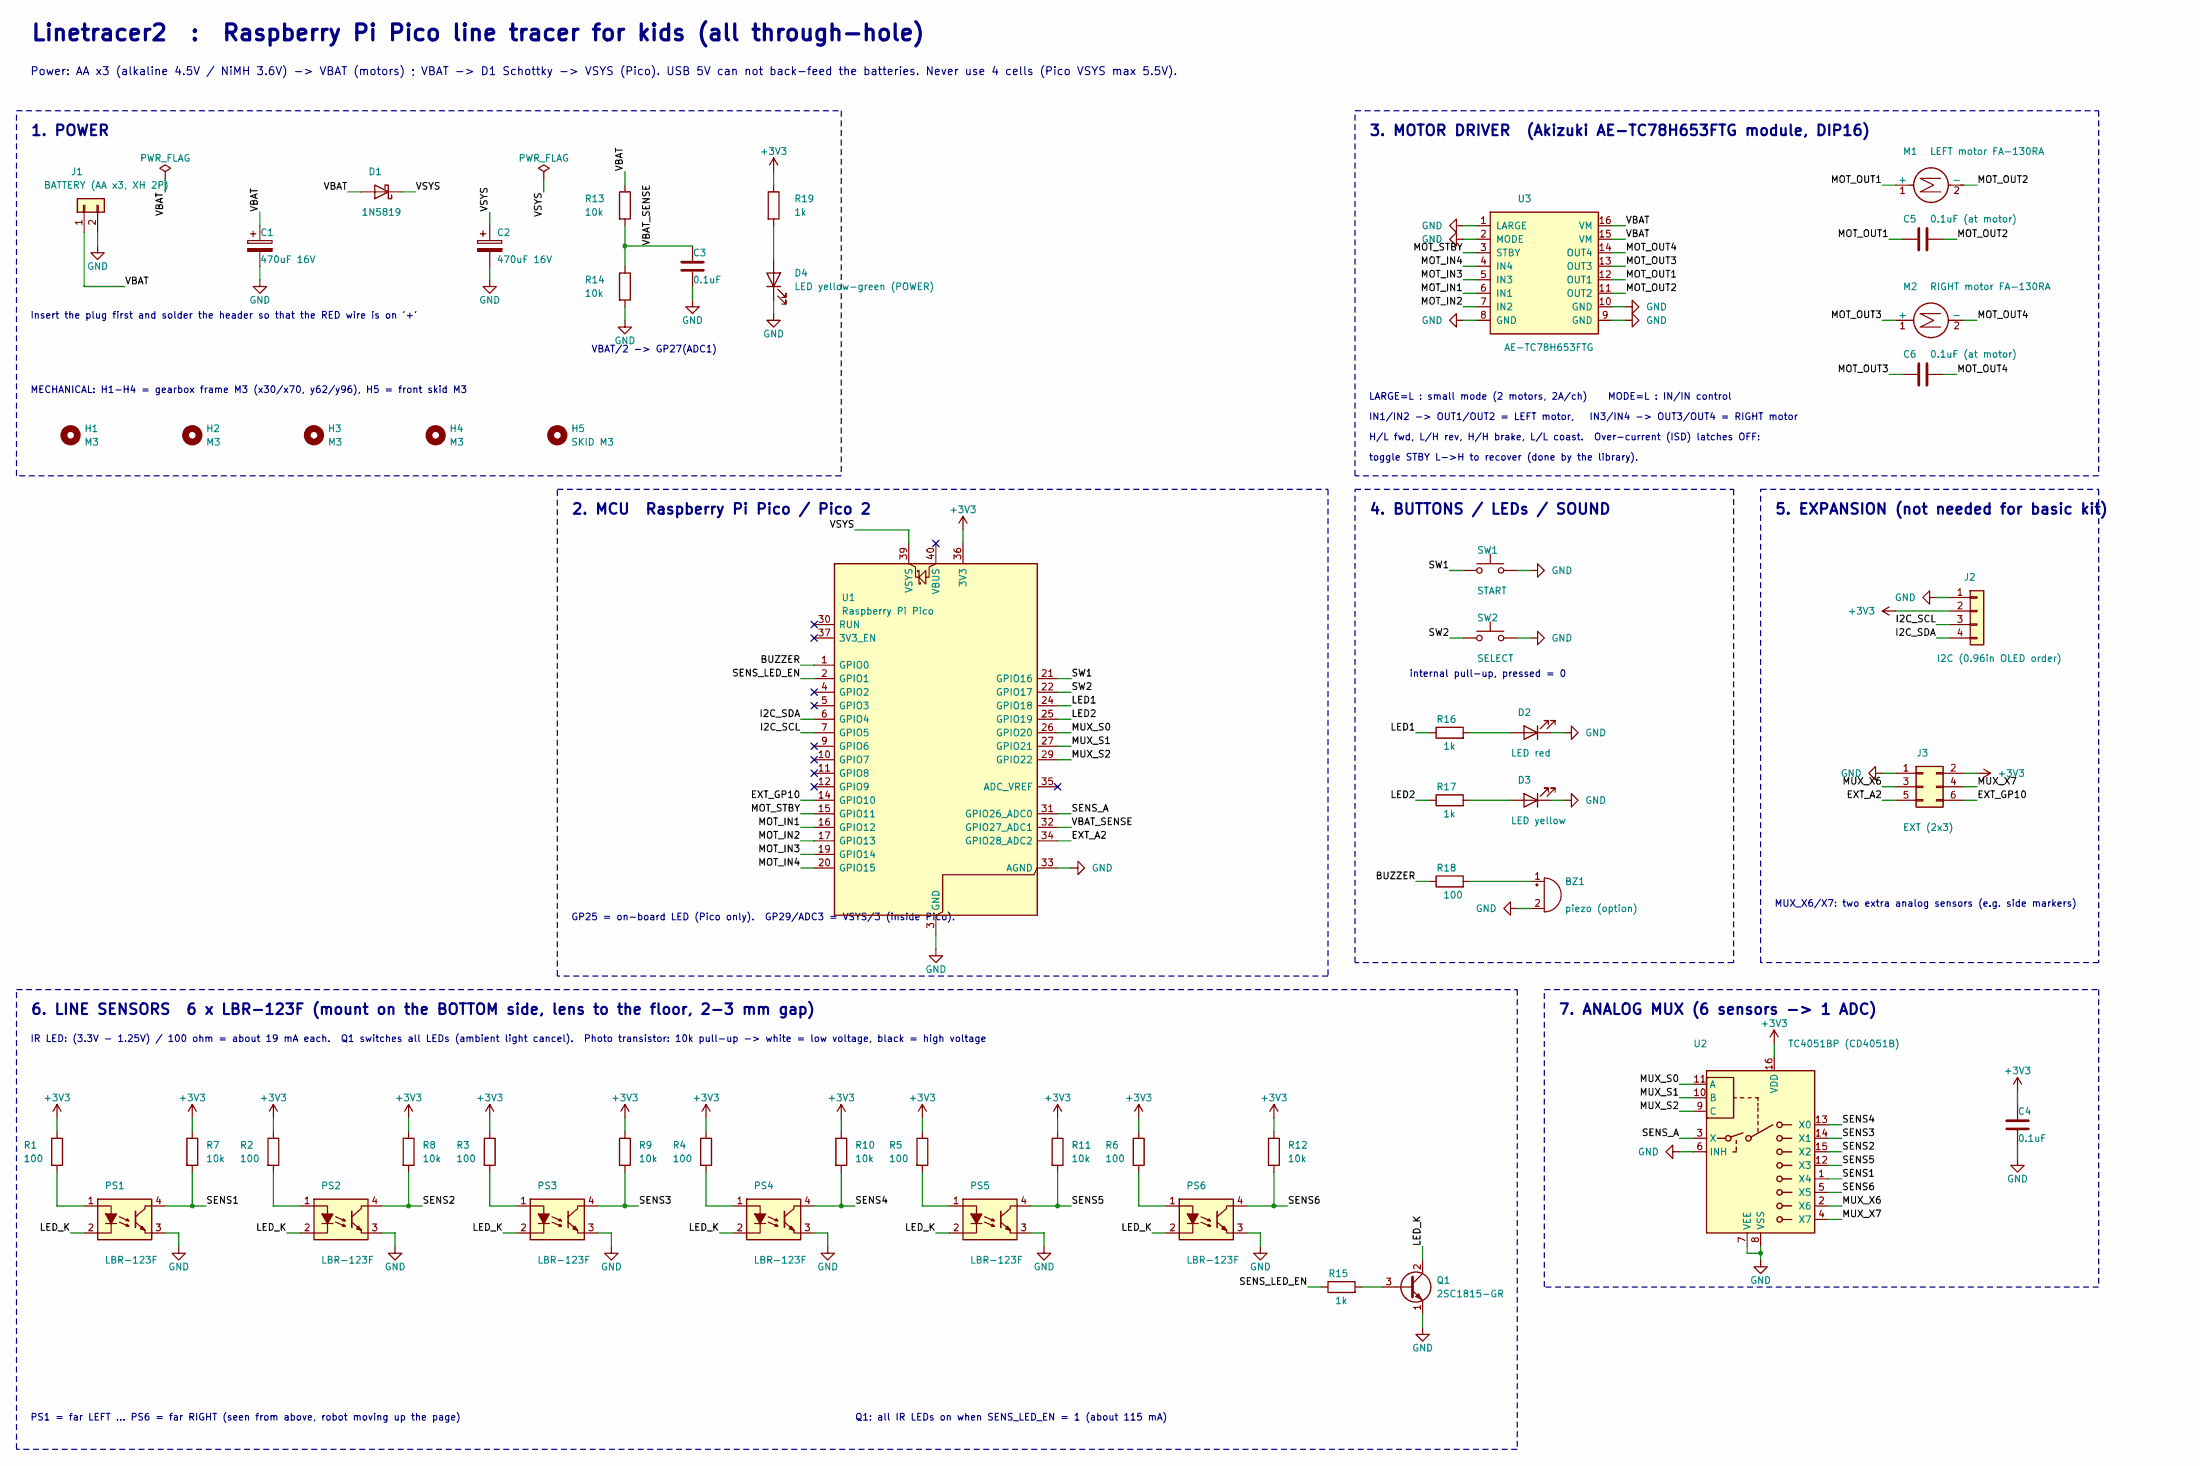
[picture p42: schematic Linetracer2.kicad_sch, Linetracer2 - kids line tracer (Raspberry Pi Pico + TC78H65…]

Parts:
BZ1: piezo (option); Buzzer_P5.0_P7.6
C1, C2: 470uF 16V; CP_Radial_D8.0mm_P3.50mm
C3, C4: 0.1uF; C_Disc_D3.0mm_W2.0mm_P2.50mm
C5, C6: 0.1uF (at motor); C_Disc_D3.0mm_W2.0mm_P2.50mm
D1: 1N5819; D_DO-41_SOD81_P10.16mm_Horizontal
D2: LED red; LED_D3.0mm
D3: LED yellow; LED_D3.0mm
D4: LED yellow-green (POWER); LED_D3.0mm
H1, H2, H3, H4: M3; MountingHole_3.2mm_M3
H5: SKID M3; MountingHole_3.2mm_M3
J1: BATTERY (AA x3, XH 2P); BatteryXH_2P
J2: I2C (0.96in OLED order); PinHeader_1x04_P2.54mm_Vertical
J3: EXT (2x3); PinHeader_2x03_P2.54mm_Vertical
M1: LEFT motor FA-130RA; MotorPads_2P_Relief
M2: RIGHT motor FA-130RA; MotorPads_2P_Relief
PS1, PS2, PS3, PS4, PS5, PS6: LBR-123F
Q1: 2SC1815-GR; TO-92_Inline_Wide
R1, R2, R3, R4, R5, R6, R18: 100; R_Axial_DIN0207_L6.3mm_D2.5mm_P10.16mm_Horizontal
R7, R8, R9, R10, R11, R12, R13, R14: 10k; R_Axial_DIN0207_L6.3mm_D2.5mm_P10.16mm_Horizontal
R15, R16, R17, R19: 1k; R_Axial_DIN0207_L6.3mm_D2.5mm_P10.16mm_Horizontal
SW1: START; SW_PUSH_6mm
SW2: SELECT; SW_PUSH_6mm
U1: Raspberry Pi Pico; RaspberryPi_Pico_Common_THT
U2: TC4051BP (CD4051B); DIP-16_W7.62mm
U3: AE-TC78H653FTG

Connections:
+3V3: C4.1, J2.2, J3.2, R1.1, R2.1, R3.1, R4.1, R5.1, R6.1, R7.1, R8.1, R9.1, R10.1, R11.1, R12.1, R19.1, U1.36 (3V3), U2.16 (VDD)
/BUZZER: R18.1, U1.1 (GPIO0)
/EXT_A2: J3.5, U1.34 (GPIO28_ADC2)
/EXT_GP10: J3.6, U1.14 (GPIO10)
/I2C_SCL: J2.3, U1.7 (GPIO5)
/I2C_SDA: J2.4, U1.6 (GPIO4)
/LED1: R16.1, U1.24 (GPIO18)
/LED2: R17.1, U1.25 (GPIO19)
/LED_K: PS1.2 (K), PS2.2 (K), PS3.2 (K), PS4.2 (K), PS5.2 (K), PS6.2 (K), Q1.2 (C)
/MOT_IN1: U1.16 (GPIO12), U3.6 (IN1)
/MOT_IN2: U1.17 (GPIO13), U3.7 (IN2)
/MOT_IN3: U1.19 (GPIO14), U3.5 (IN3)
/MOT_IN4: U1.20 (GPIO15), U3.4 (IN4)
/MOT_OUT1: C5.1, M1.1 (+), U3.12 (OUT1)
/MOT_OUT2: C5.2, M1.2 (-), U3.11 (OUT2)
/MOT_OUT3: C6.1, M2.1 (+), U3.13 (OUT3)
/MOT_OUT4: C6.2, M2.2 (-), U3.14 (OUT4)
/MOT_STBY: U1.15 (GPIO11), U3.3 (STBY)
/MUX_S0: U1.26 (GPIO20), U2.11 (A)
/MUX_S1: U1.27 (GPIO21), U2.10 (B)
/MUX_S2: U1.29 (GPIO22), U2.9 (C)
/MUX_X6: J3.3, U2.2 (X6)
/MUX_X7: J3.4, U2.4 (X7)
/SENS1: PS1.4 (C), R7.2, U2.1 (X4)
/SENS2: PS2.4 (C), R8.2, U2.15 (X2)
/SENS3: PS3.4 (C), R9.2, U2.14 (X1)
/SENS4: PS4.4 (C), R10.2, U2.13 (X0)
/SENS5: PS5.4 (C), R11.2, U2.12 (X3)
/SENS6: PS6.4 (C), R12.2, U2.5 (X5)
/SENS_A: U1.31 (GPIO26_ADC0), U2.3 (X)
/SENS_LED_EN: R15.1, U1.2 (GPIO1)
/SW1: SW1.1, U1.21 (GPIO16)
/SW2: SW2.1, U1.22 (GPIO17)
/VBAT: C1.1, D1.2 (A), J1.1, R13.1, U3.15 (VM), U3.16 (VM)
/VBAT_SENSE: C3.1, R13.2, R14.1, U1.32 (GPIO27_ADC1)
/VSYS: C2.1, D1.1 (K), U1.39 (VSYS)
GND: BZ1.2 (-), C1.2, C2.2, C3.2, C4.2, D2.1 (K), D3.1 (K), D4.1 (K), J1.2, J2.1, J3.1, PS1.3 (E), PS2.3 (E), PS3.3 (E), PS4.3 (E), PS5.3 (E), PS6.3 (E), Q1.1 (E), R14.2, SW1.2, SW2.2, U1.3 (GND), U1.8 (GND), U1.13 (GND), U1.18 (GND), U1.23 (GND), U1.28 (GND), U1.33 (AGND), U1.38 (GND), U2.6 (INH), U2.7 (VEE), U2.8 (VSS), U3.1 (LARGE), U3.2 (MODE), U3.8 (GND), U3.9 (GND), U3.10 (GND)
unnamed: BZ1.1 (+), R18.2
unnamed: D2.2 (A), R16.2
unnamed: D3.2 (A), R17.2
unnamed: D4.2 (A), R19.2
unnamed: PS1.1 (A), R1.2
unnamed: PS2.1 (A), R2.2
unnamed: PS3.1 (A), R3.2
unnamed: PS4.1 (A), R4.2
unnamed: PS5.1 (A), R5.2
unnamed: PS6.1 (A), R6.2
unnamed: Q1.3 (B), R15.2

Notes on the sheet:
6. LINE SENSORS 6 x LBR-123F (mount on the BOTTOM side, lens to the floor, 2-3 mm gap)
7. ANALOG MUX (6 sensors -> 1 ADC)
Power: AA x3 (alkaline 4.5V / NiMH 3.6V) -> VBAT (motors) ; VBAT -> D1 Schottky -> VSYS (Pico). USB 5V can not back-feed the batteries. Never use 4 cells (Pico VSYS max 5.5V).
GP25 = on-board LED (Pico only). GP29/ADC3 = VSYS/3 (inside Pico).
Insert the plug first and solder the header so that the RED wire is on '+'
2. MCU Raspberry Pi Pico / Pico 2
4. BUTTONS / LEDs / SOUND
1. POWER
IR LED: (3.3V - 1.25V) / 100 ohm = about 19 mA each. Q1 switches all LEDs (ambient light cancel). Photo transistor: 10k pull-up -> white = low voltage, black = high voltage
LARGE=L : small mode (2 motors, 2A/ch) MODE=L : IN/IN control
internal pull-up, pressed = 0
toggle STBY L->H to recover (done by the library).
Q1: all IR LEDs on when SENS_LED_EN = 1 (about 115 mA)
H/L fwd, L/H rev, H/H brake, L/L coast. Over-current (ISD) latches OFF:
5. EXPANSION (not needed for basic kit)
MUX_X6/X7: two extra analog sensors (e.g. side markers)
MECHANICAL: H1-H4 = gearbox frame M3 (x30/x70, y62/y96), H5 = front skid M3
VBAT/2 -> GP27(ADC1)
PS1 = far LEFT ... PS6 = far RIGHT (seen from above, robot moving up the page)
IN1/IN2 -> OUT1/OUT2 = LEFT motor, IN3/IN4 -> OUT3/OUT4 = RIGHT motor
Linetracer2 : Raspberry Pi Pico line tracer for kids (all through-hole)
3. MOTOR DRIVER (Akizuki AE-TC78H653FTG module, DIP16)

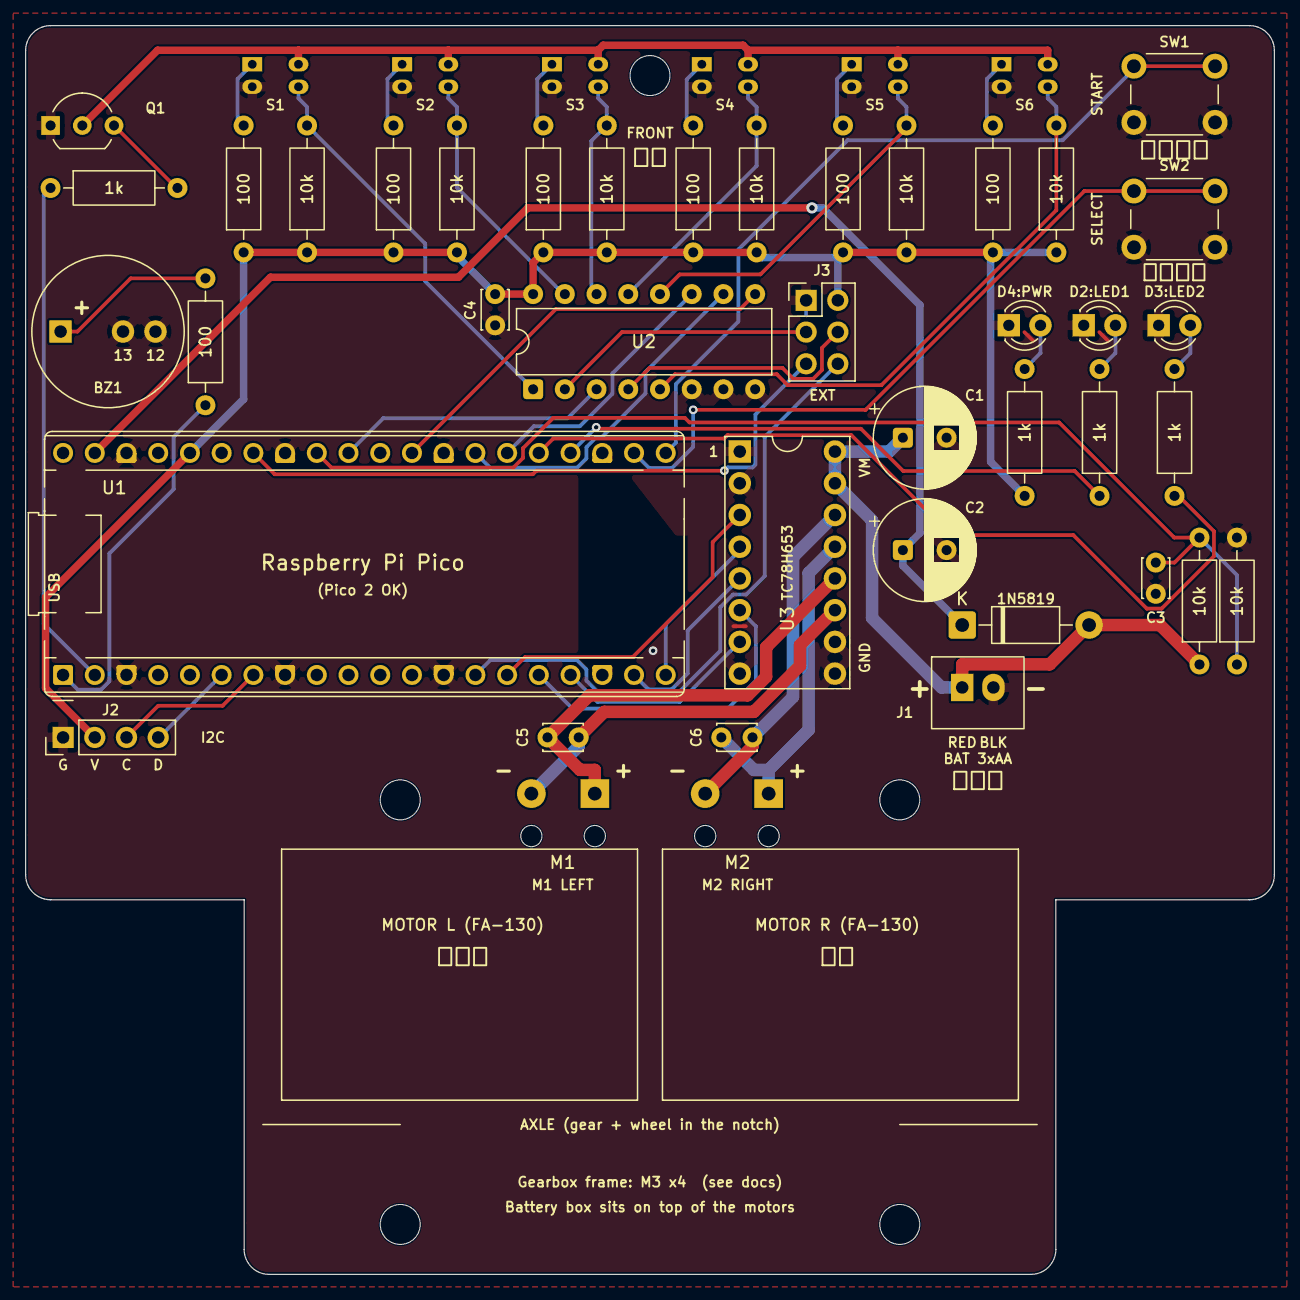
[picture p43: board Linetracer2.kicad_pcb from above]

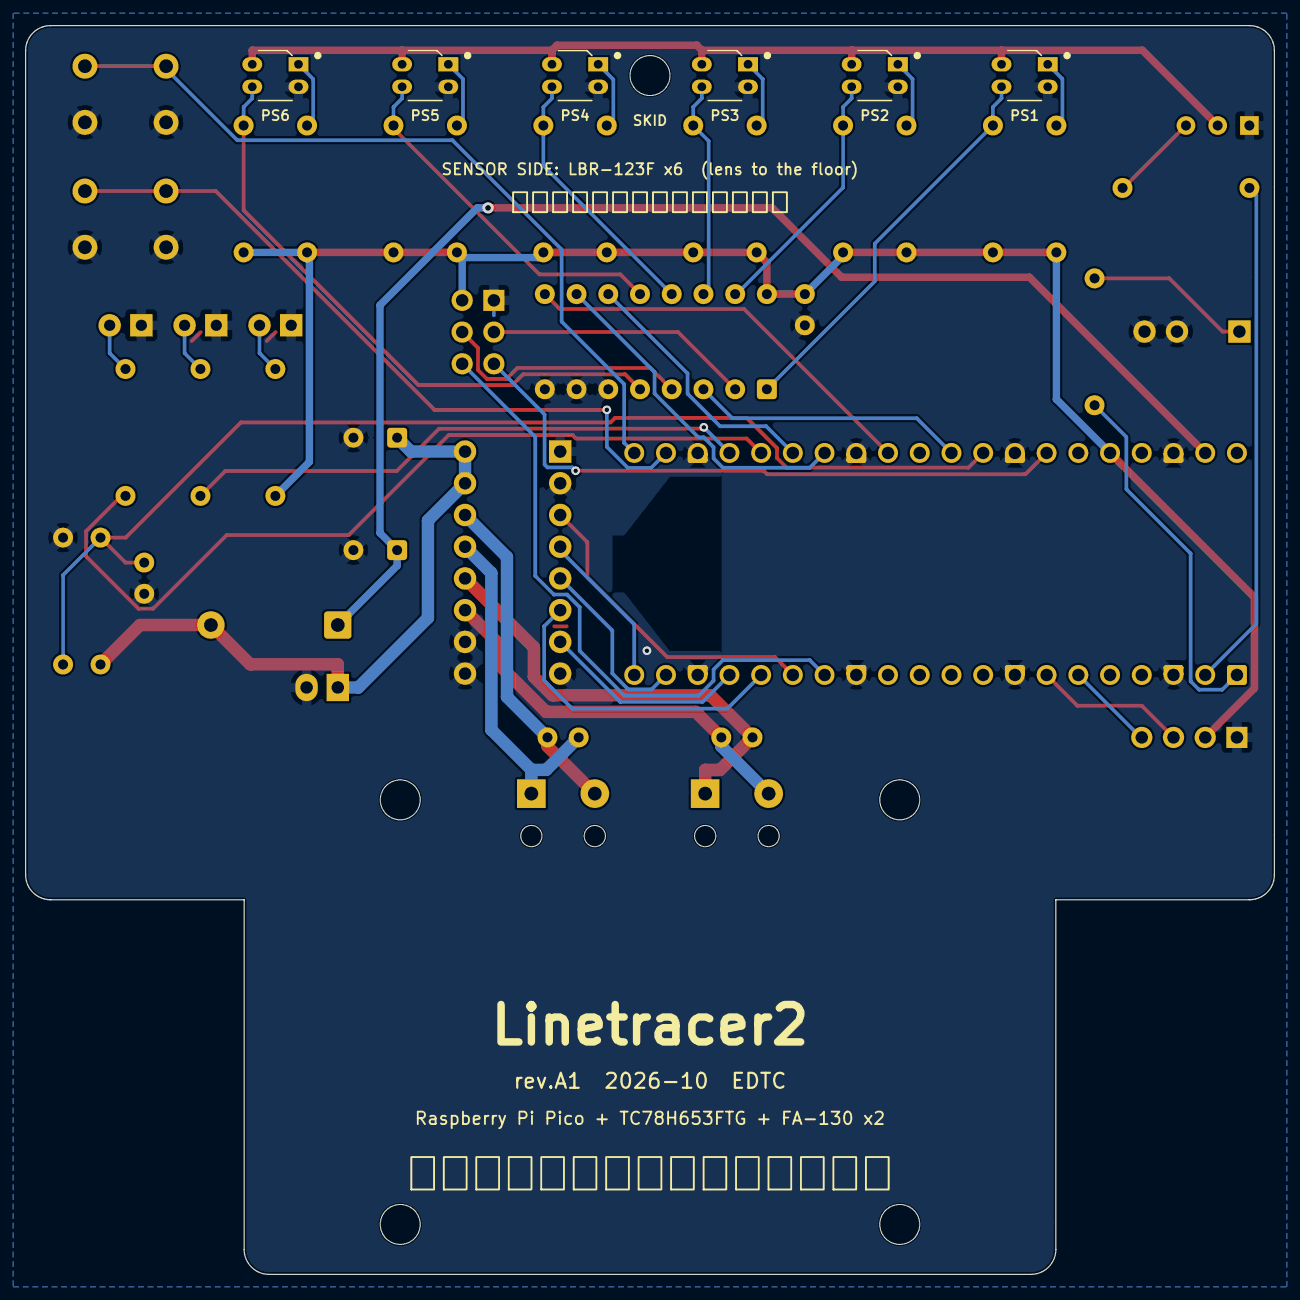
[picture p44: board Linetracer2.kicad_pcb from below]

Board: 2 copper layers, 100.0 x 100.0 mm, 52 parts (6 on the bottom side), 48 nets.

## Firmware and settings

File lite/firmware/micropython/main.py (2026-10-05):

# main.py  -  Linetracer2 Lite standard program (PD line following, 3 sensors)
#
#   START short press : 1st time = auto calibration (robot spins on the line)
#                       after that = run.  Press START again to stop.
#   START long press  : change speed level 1..3 (hold until the Pico's LED lights, then let go;
#                       the red LED blinks the new level)
#   red LED on        : ready (the Lite board has no power LED)
#
# Put the robot on the line before pressing START.

import time
from linetracer import Robot

robot = Robot()
m, s = robot.motors, robot.sensors

# speed level -> (base speed %, Kp, Kd)   100 % = 3.0 V on the motors
# Position is -1000 .. +1000 (3 sensors, 12 mm apart), so Kp is larger than on the 6-sensor board.
# (starting values - tune them on your course: Kp first, then Kd)
LEVELS = {
    1: (30, 0.025, 0.35),     # slow
    2: (45, 0.032, 0.50),     # medium
    3: (60, 0.040, 0.65),     # fast
}
level = 1


def run_course(base, kp, kd):
    s.ambient_cancel = True
    last_err = 0
    d_f = 0.0
    lost_since = None
    t_prev = time.ticks_us()
    robot.led.value(0)
    robot.wait_release()
    while not robot.start_pressed():
        pos = s.position()
        now = time.ticks_us()
        dt = max(1, time.ticks_diff(now, t_prev)) / 1000.0   # ms
        t_prev = now
        if pos is None:
            # line lost: turn hard to the side where it was last seen
            if lost_since is None:
                lost_since = time.ticks_ms()
            if time.ticks_diff(time.ticks_ms(), lost_since) > 800:
                break                       # gave up (off the course)
            turn = 60 if s.last_pos > 0 else -60
            m.run(base * 0.3 + turn, base * 0.3 - turn)
            continue
        lost_since = None
        err = pos                           # -1000 .. +1000  (+ = line is right)
        d = (err - last_err) / dt           # change per millisecond
        d_f += (d - d_f) * 0.3              # smooth it: with 3 sensors the position moves in steps
        last_err = err
        steer = kp * err + kd * d_f
        m.run(base + steer, base - steer)
    m.brake()
    time.sleep_ms(300)
    m.stop()
    robot.led.value(1)


robot.blink(1)
ok, v = robot.battery_ok()
if robot.battery.usb():
    print("USB connected (battery not measured). Motors run only with the battery switch ON.")
else:
    print("battery %.2f V" % v)
if not ok:
    robot.blink(5, 60)                      # low battery
robot.led.value(1)                          # ready

while True:
    kind = robot.wait_press()
    if kind == "long":
        level = level % len(LEVELS) + 1
        print("level", level)
        time.sleep_ms(300)
        robot.led.value(0)
        time.sleep_ms(300)
        robot.blink(level, 200)
        robot.led.value(1)
        continue
    if not s.calibrated():
        robot.led.value(0)
        ok = robot.auto_calibrate()
        print("calibrated" if ok else "calibration failed", s.lo, s.hi)
        if not ok:
            robot.blink(4, 300)
        robot.led.value(1)
        continue
    robot.blink(3, 80)                      # ready...
    base, kp, kd = LEVELS[level]
    run_course(base, kp, kd)
    robot.wait_release()

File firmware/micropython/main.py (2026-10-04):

# main.py  -  Linetracer2 standard program (PD line following)
#
#   SELECT (SW2) : change speed level 1..3  (LED1 = 1, LED2 = 2, both = 3, + beeps)
#   START  (SW1) : 1st press = auto calibration (robot spins on the line)
#                  2nd press = run.  Press START again to stop.
#
# Put the robot on the line before pressing START.

import time
from linetracer import Robot

robot = Robot()
m, s = robot.motors, robot.sensors

# speed level -> (base speed %, Kp, Kd)   100 % = 3.0 V on the motors
# (starting values - tune them on your course: Kp first, then Kd)
LEVELS = {
    1: (30, 0.012, 0.35),     # slow
    2: (45, 0.016, 0.50),     # medium
    3: (60, 0.020, 0.65),     # fast
}
level = 1


def show_level(lv):
    robot.led1.value(lv & 1)
    robot.led2.value((lv >> 1) & 1)


def run_course(base, kp, kd):
    s.ambient_cancel = True
    last_err = 0
    lost_since = None
    t_prev = time.ticks_us()
    robot.wait_release()
    while not robot.start_pressed():
        pos = s.position()
        now = time.ticks_us()
        dt = max(1, time.ticks_diff(now, t_prev)) / 1000.0   # ms
        t_prev = now
        if pos is None:
            # line lost: turn hard to the side where it was last seen
            if lost_since is None:
                lost_since = time.ticks_ms()
            if time.ticks_diff(time.ticks_ms(), lost_since) > 800:
                break                       # gave up (off the course)
            turn = 60 if s.last_pos > 0 else -60
            m.run(base * 0.3 + turn, base * 0.3 - turn)
            continue
        lost_since = None
        err = pos                           # -2500 .. +2500  (+ = line is right)
        d = (err - last_err) / dt           # change per millisecond
        last_err = err
        steer = kp * err + kd * d
        m.run(base + steer, base - steer)
    m.brake()
    time.sleep_ms(300)
    m.stop()


robot.buzzer.beep(1, 1500)
ok, v = robot.battery_ok()
print("battery %.2f V" % v)
if not ok:
    robot.buzzer.beep(5, 800, 120)          # low battery (or USB only)

show_level(level)
while True:
    if robot.select_pressed():
        level = level % len(LEVELS) + 1
        show_level(level)
        robot.buzzer.beep(level, 2500, 40)
        robot.wait_release()
    if robot.start_pressed():
        robot.wait_release()
        if not s.calibrated():
            robot.buzzer.beep(2, 1200)
            ok = robot.auto_calibrate()
            print("calibrated" if ok else "calibration failed", s.lo, s.hi)
            robot.buzzer.beep(1 if ok else 4, 2000 if ok else 600)
            continue
        robot.buzzer.beep(3, 3000, 50)       # ready...
        base, kp, kd = LEVELS[level]
        run_course(base, kp, kd)
        robot.buzzer.beep(1, 1000, 200)
        robot.wait_release()
    time.sleep_ms(20)

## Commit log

2026-10-04 Linetracer2 rev.A1: 子ども向け教材ライントレーサー一式
    - 要件定義・構成・駆動系計算・回路・基板・BOM・組立手順・ソフト・知見メモ (docs/)
    - KiCad 10 プロジェクト (ERC 0、DRC エラー 0・未接続 0) と Gerber (rev.A1)
    - 3D プリント部品 (OpenSCAD): 枠 L/R、電池ボックスをねじ止めするデッキ、
    印刷用 40T 平歯車、車輪、スキッド (高さ 3 種)。干渉チェック済み
    - 部品は秋月・ホームセンター・タミヤ品など T 番号のある店で買える物だけ
    - MicroPython ライブラリ・本番プログラム・授業用サンプル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
    [Linetracer2-B_Cu.gbl, Linetracer2-B_Mask.gbs, Linetracer2-B_Silkscreen.gbo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]
2026-10-04 平歯車の印刷可否をスライサーで確認、印刷時間の目安を追加
    - Bambu Studio 2.08 CLI で P1S 0.4mm 用にスライスし、G コードから歯ごとの外壁半径を測定
    - 壁の生成「クラシック」(既定) なら 40 枚すべて先端まで印刷される
    - Arachne では 2 枚欠落・3 枚欠け → 使わないよう README に明記
    - 平歯車の推奨設定を 壁 4・インフィル 40% に (100% はスライス不可だった)
    - 部品ごとの印刷時間 (1 台分 約 2 時間) を追記
2026-10-04 Bambu Studio CLI の出力 result.json を削除・無視
2026-10-04 全体組み立ての 3D（assembly.stl）と部品付き基板の STEP を追加
    [Linetracer2_pcb.step, assembly.stl]
2026-10-04 スキッドをツメ式に、電池ボックスをツメで留めるデッキ（任意）を追加
    - skid_clip_h35/40/45: 2 本に割れたピンで基板の穴に押し込むそり形スキッド
    （横倒し印刷で層に沿って曲がる向き）。ねじとナイロンナットが不要に
    - deck_clip: 底の穴に入る突起で位置決めし、4 本のツメで電池ボックスを押さえる任意版
    （電池ボックスの壁の高さ BOX_SHOULDER_H を実物で合わせる）
    - 基板・枠・デッキはねじのまま（荷重・クリープ・印刷向きの理由を記載）
    - 干渉チェックを追加（陽性対照で検出できることも確認）、P1S でス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
    [assembly.stl, deck_clip.stl, linetracer2_mech.scad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]
2026-10-04 低コスト版 Linetracer2 Lite（rev.L1）を追加
    標準版 rev.A1 はそのまま残し、同じスクリプトで LT2_VARIANT=lite を付けると
    hardware/lite/ に Lite の回路図・基板・Gerber が生成されるようにした。
    - Pico をピンヘッダなしで基板にじかにはんだ付け（専用フットプリント）
    - センサー 3 個を ADC に直結（TC4051BP なし）、電池電圧は Pico 内部の VSYS/3（GP29）
    - ブザーなし、LED 1 個、ボタン 1 個、I2C は穴だけ
    - O リングの代わりに TPU 印刷タイヤ、スキッドは (50,11) に移動して鉄ナット
    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
    [Linetracer2-Lite-B_Cu.gbl, Linetracer2-Lite-B_Mask.gbs, Linetracer2-Lite-B_Silkscreen.gbo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]
2026-10-05 ボールキャスター（試作）を 2 種類追加: 玉ごと印刷版とダイソーのビーズ版
    - caster_print_h40: 受けと φ6 の玉を一度に印刷（プリントインプレース）
    - caster_bead_h40: 受けだけ印刷し、ダイソーのパール調ビーズ φ6 を床側から押し込む
    - どちらもツメ式スキッドと同じピンで SKID の穴に差し込む。φ6 の玉は基板と床の
    すき間 4.0 mm に入らないので、基板の前の端より前に出し、腕でピンにつなぐ
    - 横倒しで印刷（ピンとビーズを押さえる指が層に沿って曲がる向き）
    - 干渉チェック 4 つを追加（陽性対照で検出できるこ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
    [caster_bead_h40.stl, caster_print_h40.stl, linetracer2_mech.scad]
2026-10-05 Lite 一式を lite/ フォルダにまとめ、標準版のファイルと分けた
    - lite/README.md（設計書）、lite/docs/、lite/hardware/、lite/firmware/micropython/、lite/scripts/
    - 共通スクリプト（scripts/）は LT2_VARIANT=lite で lite/hardware/ に出力し、Lite 専用の生成スクリプトは lite/scripts/ から呼ぶ
    - 新しい配置から手順を通しで再実行: ERC 0、DRC エラー 0・警告 0・未接続 0
    [Linetracer2-Lite-B_Cu.gbl, Linetracer2-Lite-B_Mask.gbs, Linetracer2-Lite-B_Silkscreen.gbo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]
2026-10-05 玉ごと印刷版のボールキャスターを φ4 に小さくし、そり形にした
    - 玉 φ6 → φ4: 受けが基板の上面より低くなり、ツメのスキッドと同じ幅 5 mm に収まる
    （前への出っぱり 7.7 → 4.7 mm）
    - 腕と玉の受けを hull でつないだそり形に（ビーズ版も同じ形）
    - すき間 0.3 → 0.35 mm: φ4 では G コード上の空きが約 0.22 mm しかなかったため。
    0.35 mm で約 0.27 mm、玉の上は空の層 4 層（P1S でスライスして確認）
    - 印刷時間 約 4.5 分（両方）
    [caster_bead_h40.stl, caster_print_h40.stl, linetracer2_mech.scad]
2026-10-13 Lite rev.L3: XIAO（ピンヘッダ）、ブザー、フルカラー LED 6 こ、テストパッド、手で引いた配線、車軸も印刷するギヤボックス (#4)
    * Lite rev.L2: XIAO ESP32C6 と LBR-127HLD に変更、子ども向けに配置・シルクを見直し
    - マイコンを Seeed Studio XIAO ESP32C6（秋月 129481）に。ピンヘッダなしで基板にじかにはんだ付け
    （自作フットプリント: 裏のテストパッドの下は銅禁止、USB の足の逃げ穴、アンテナの下は両面銅なし）
    - フォトリフレクタを LBR-127HLD（秋月 104500）に。背が 5.6 mm あるのでスキッドを 7.5 mm に
    （skid_clip_h70/h75/h80.stl、ロ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
2026-10-13 ギヤの軸間を 0.1 mm 広げ、モーターの端子の逃げを付けた
    - 回すとコリコリ鳴るので、軸間 12.0 → 12.1 mm（GEAR_CD_ADD、モーターを 0.1 mm 前へ。車軸と基板はそのまま）
    - モーターの端子は缶の外形の内側に描いていて、ゆりかごの壁のうしろの端に当たるのが見えなかった。
    大きめのよけておく箱（TERM_*）で描き直し、壁のうしろの端に外へ抜けた切り欠きを付けた
    - 新しいチェック check_terminal_other（ずらして入れるモーターのおしりと、もう片方の枠）
    - 枠・デッキ・ツメ版デッキ・組み立て図の STL を書き出し直した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
2026-10-13 ギヤの軸間をさらに広げた: GEAR_CD_ADD 0.10 → 0.15（軸間 12.15 mm）
    - モーター軸 y 75.9 → 75.85。かみ合い率 1.23。これ以上は広げない（軸受けのガタで 1 を切る）
    - 枠・デッキ・ツメ版デッキ・組み立て図の STL を書き出し直した。干渉チェックは標準・Lite とも全部空
    Claude-Session: https://claude.ai/code/session_01BoHoZdgE9SykAB5hpUrW3b
2026-10-13 軸間は 0.10 に戻し、平歯車の歯を細くした（GEAR_BACKLASH 0.10 → 0.15）
    - GEAR_CD_ADD 0.15 → 0.10（軸間 12.1 mm、モーター軸 y 75.9、かみ合い率 1.32）
    - GEAR_BACKLASH 0.15。gear40・枠・デッキ・ツメ版デッキ・組み立て図の STL を書き出し直した
    - 干渉チェックは標準・Lite とも全部空
    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
2026-10-14 Lite の印刷セット（zip）を追加: プレート別のフォルダ、印刷リスト付き
    - lite/hardware/Linetracer2-Lite_print_set.zip: 枠 2・デッキ・平歯車 2・車輪 2・キャスター・TPU タイヤ 2
    - scripts/make_print_set.sh で作り直せる（STL を書き出し直したら実行）
    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
2026-10-14 車輪のグラつきを減らした: 軸受けのすき間を詰め、奥の軸受けを深く
    - ハブと外かべの穴 +0.5 → +0.3、車軸と奥の軸受け +0.35 → +0.25、前後のすき間 0.5 → 0.4
    - 奥の軸受けの底 x 19.3 → 19.9（缶の前の面まで壁 0.6 mm）。車軸も 0.6 mm 長く
    - 最悪の場合の計算（scad の echo）: リムの端の振れ ±0.72 → ±0.45 mm、平歯車の中心 ±0.21 → ±0.14 mm
    - 車輪・左右の枠・組み立て図の STL と印刷セットの zip を書き出し直した。干渉チェックは標準・Lite とも全部空
    （わざとずらした条件では検出）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
2026-10-26 Lite: Arduino（C++）版のソフトを追加（ライントレース・動作チェック・スマホで操作）
    lite/firmware/arduino/ に XIAO ESP32C6（rev.L3）用の Arduino ライブラリ Linetracer2Lite を追加。
    ピン・設定・動きは MicroPython の linetracer.py / main.py と同じ。
    - 01_LineTrace: main.py と同じ操作の PD ライントレース
    - 02_SelfTest: 先生用の動作チェック（LED・ブザー・ボタン・センサー・モーター・Wi-Fi）
    - 03_WiFiControl: ロボットが Wi-Fi の電波を出し、スマホのブラウザでラジコンのように動かす
    esp32 3.3.11 でコンパイルを確認（警告なし）。実機ではまだ動か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
2026-10-28 Lite Arduino: スマホのパッドで前後が逆になるのを直した（motors.reverse）
    Motors に reverse を追加（左右のモーターを入れかえて両方逆に回す = 前と後ろを入れかえ、
    回る向きはそのまま）。03_WiFiControl では REVERSE = true。
